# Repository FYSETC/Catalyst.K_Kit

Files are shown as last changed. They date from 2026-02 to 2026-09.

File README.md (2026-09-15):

# Catalyst.K
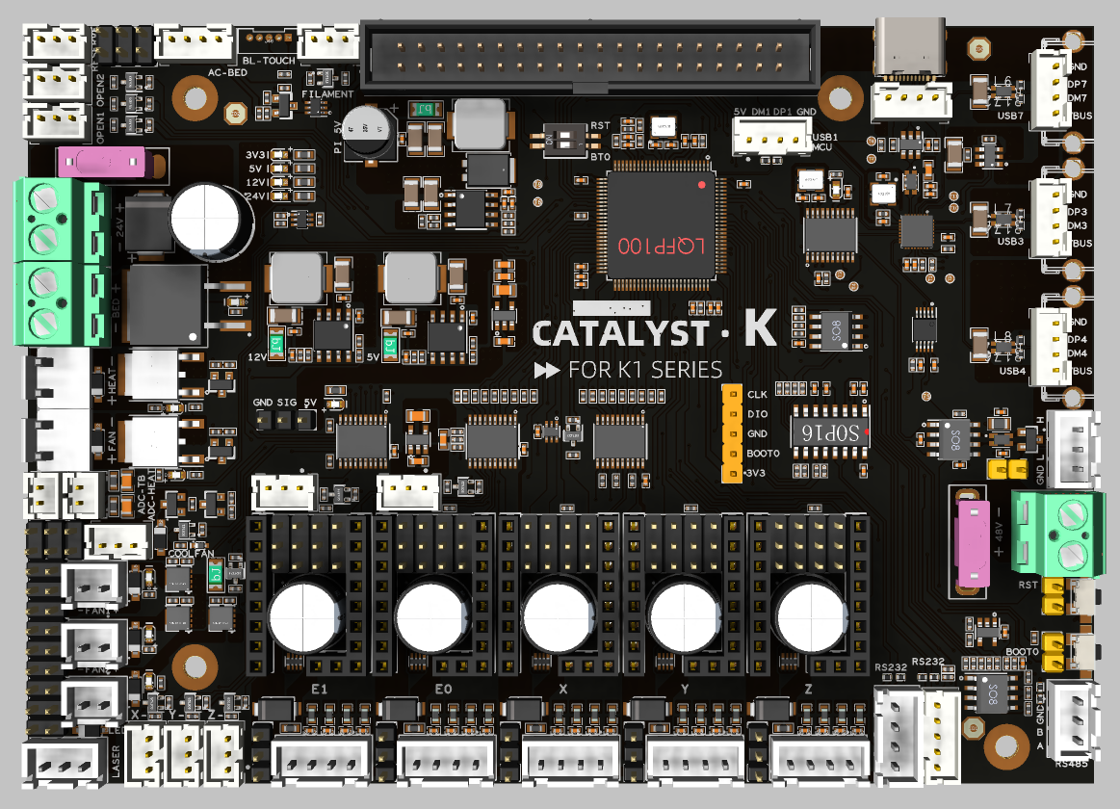
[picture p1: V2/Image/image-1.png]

# Introduction
This high‑performance 3D printer mainboard is built around an STM32H723 32‑bit MCU and comes in a 138 mm × 98 mm form factor. Designed for modern open‑source firmware such as Klipper, it connects to external SBCs like Raspberry Pi 3B+/4B/5B via USB to form a powerful “MCU + SBC” architecture, enabling high‑speed printing, multi‑axis motion control, and advanced feature expansion.

# Features
- High‑performance MCU based on STM32H723 for demanding 3D printing workloads such as high‑speed interpolation and synchronized multi‑axis motion control.
- Native support for Klipper‑style setups via USB connection to Raspberry Pi 3B+/4B/5B or any Klipper‑compatible host.
- Five STEPSTICK sockets supporting flexible driver choices such as TMC5160 and TMC2209 to balance torque, smoothness, and silent operation.
- Selectable 24V/48V stepper motor supply with per‑motor voltage selection for mixed‑voltage motion systems.
- DC 24V input with 24V/10 A heated bed output, AC bed control signal output, and up to 5A hotend heater output for high‑power applications.
- On‑board regulated rails: 12V/3A, 5V/3A, 5V/6A (for Raspberry Pi power), and 3.3V/800 mA to power fans, sensors, and SBCs from a single board.
- Rich connectivity including 3× USB, 2× RS‑232, 1× RS‑485, and 1× high‑speed CAN interface for advanced expansions and distributed motion systems.
- Nine general‑purpose IOs and five fan outputs, with four voltage‑selectable (5V/12V/24V), plus an RGB header for status indication and lighting effects.

-------

# Applications
- Ideal as the main controller for mid‑ to high‑end FDM 3D printers, especially Klipper‑based high‑speed and multi‑axis systems.
- Suitable for upgrading existing printers from legacy 8‑bit or low‑performance boards to an STM32H7 + Klipper platform for higher speed and greater flexibility.
- Can be used in other motion‑control equipment requiring up to five stepper axes, 24 V / 48 V mixed supplies, and rich communication interfaces, such as small CNC machines, automation rigs, and laboratory devices.

# Catalyst.K ToolHead
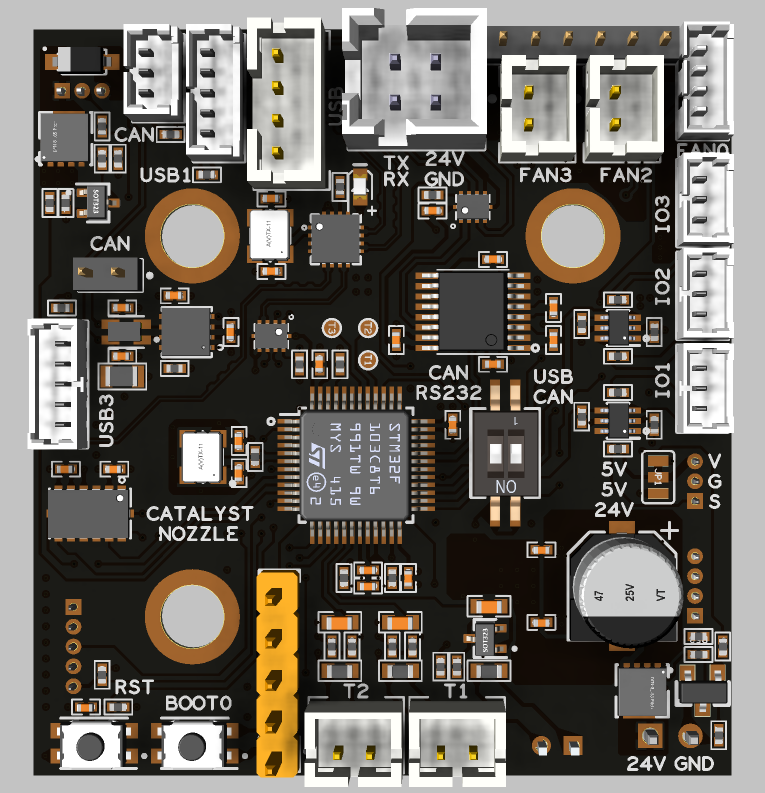
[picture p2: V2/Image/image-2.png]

# Introduction

CATALYST_NOZZLE is a compact Klipper toolboard with a footprint of only 47 mm × 44 mm, designed to be mounted close to the printhead or extruder. It is powered by an STM32G431CBT6 32‑bit MCU and supports multiple communication modes, including USB and CAN / RS‑232, which can be switched via an on‑board physical button.
The board integrates a TMC2209 stepper motor driver, an ADXL345 3‑axis accelerometer, multiple fan and temperature inputs, as well as BL‑Touch and hotend heater control. This greatly simplifies toolhead wiring, reduces cable bundle weight on moving parts, and improves overall reliability and serviceability of the printer.

# Features 
- Compact toolboard design: 47 mm × 44 mm, mounted directly near the printhead or extruder to greatly simplify wiring.
- STM32G431 MCU: 32‑bit high‑performance controller optimized for Klipper multi‑MCU setups.
- Multiple communication modes: Supports USB, CAN, and RS‑232, switchable via on‑board button.
- On‑board USB hub: Provides 3× USB ports and 1× CAN port for easy host and expansion connectivity.
- Integrated TMC2209: On‑board 24V‑powered TMC2209 stepper driver for silent, precise extruder control.
- Built‑in ADXL345: On‑board 3‑axis accelerometer for Klipper input shaping and resonance testing.
- Stable power outputs: 24V input (max. 28V) with on‑board 5V@3A and 3.3V@0.8A rails.
- Rich IO and fan interfaces: 4 level‑shifted IO pins, 4 fan outputs (2×2‑wire with selectable 5V/24V, 1×3‑wire, 1×4‑wire).
- Complete sensing and actuator interfaces: 3 temperature inputs, 1 BL‑Touch connector, 1 hotend heater output up to 2.5A.
- Easy debugging: On‑board BOOT0 and RESET buttons for quick flashing and debugging.

# Applications 
- Used as a Klipper toolhead board for extruder/printhead control, providing local motor drive, temperature control, fan control, and acceleration measurement on the toolhead to greatly simplify the printer’s wiring.
- Suitable for mid‑ to high‑end FDM 3D printers that require integrated TMC2209, ADXL345, BL‑Touch, and multiple fan/temperature interfaces, both for upgrading existing machines and for new printer designs.
- Applicable in multi‑toolhead, multi‑nozzle, or remote‑extrusion setups as a distributed toolboard node, connected to the Klipper host system via CAN or USB /RS‑232 to build flexible multi‑MCU motion control architectures.

# Pin Out

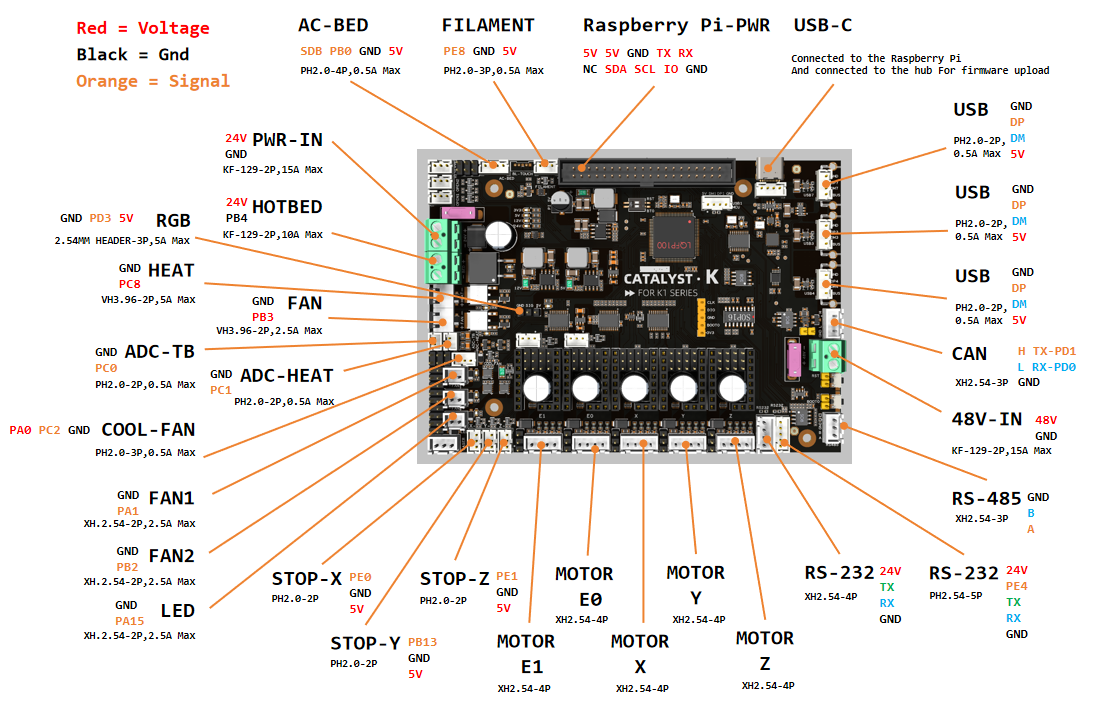
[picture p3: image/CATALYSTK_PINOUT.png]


# Communication Methods
- USB
- CAN
- RS-232

See [Wiki](https://wiki.fysetc.com/docs/CATALYST-K) for specific wiring.
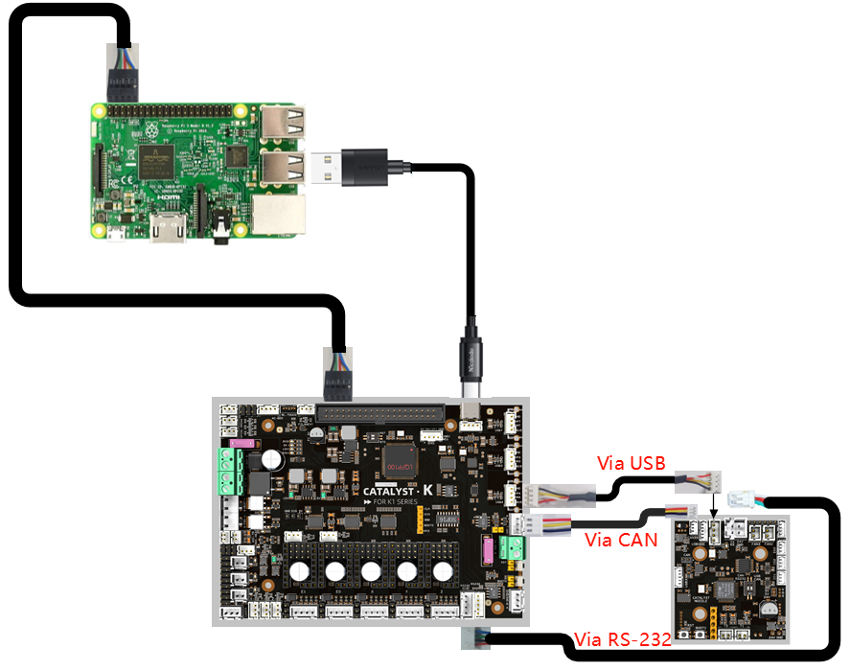
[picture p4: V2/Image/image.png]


# Reference
[Catalyst.K](https://wiki.fysetc.com/docs/CATALYST-K)

[Catalyst.K ToolHead](https://wiki.fysetc.com/docs/Catalyst-K-ToolHead)

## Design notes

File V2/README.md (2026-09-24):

# Catalyst.K
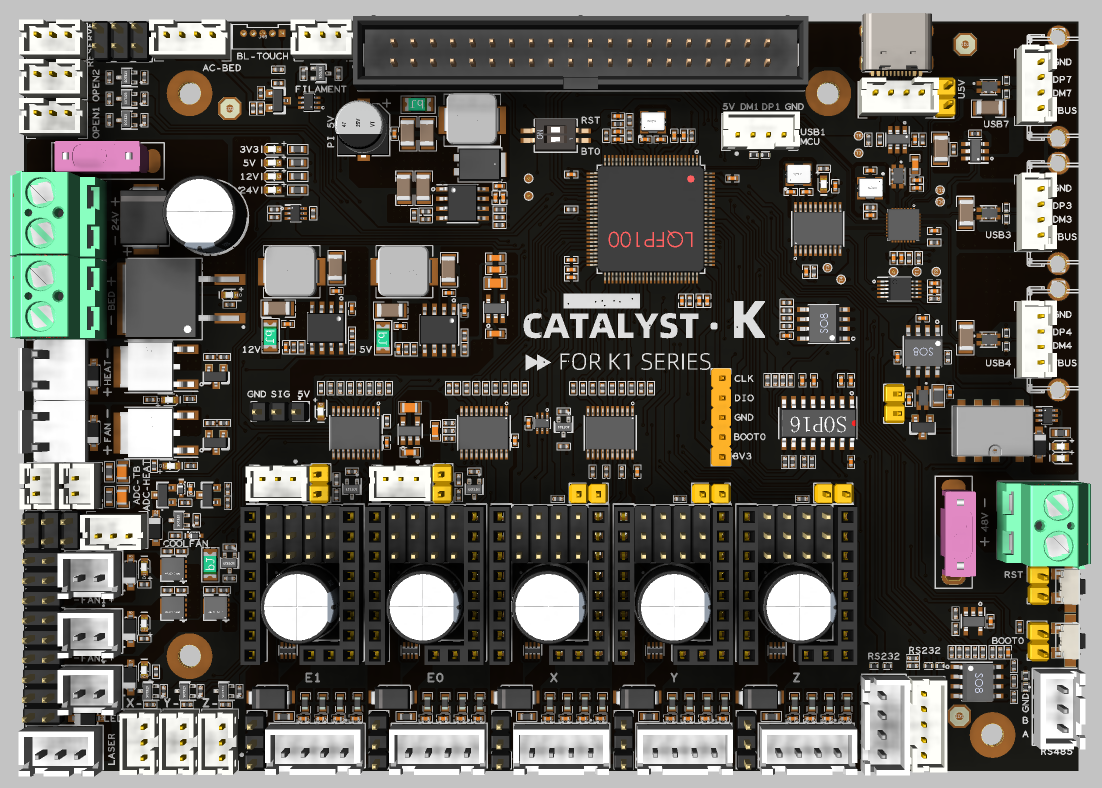
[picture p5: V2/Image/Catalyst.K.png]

## Introduction
This high‑performance 3D printer mainboard is built around an STM32H723 32‑bit MCU and comes in a 138 mm × 98 mm form factor. Designed for modern open‑source firmware such as Klipper, it connects to external SBCs like Raspberry Pi 3B+/4B/5B via USB to form a powerful “MCU + SBC” architecture, enabling high‑speed printing, multi‑axis motion control, and advanced feature expansion.

## Features
- High‑performance MCU based on STM32H723 for demanding 3D printing workloads such as high‑speed interpolation and synchronized multi‑axis motion control.
- Native support for Klipper‑style setups via USB connection to Raspberry Pi 3B+/4B/5B or any Klipper‑compatible host.
- Five STEPSTICK sockets supporting flexible driver choices such as TMC5160 and TMC2209 to balance torque, smoothness, and silent operation.
- Selectable 24V/48V stepper motor supply with per‑motor voltage selection for mixed‑voltage motion systems.
- DC 24V input with 24V/10 A heated bed output, AC bed control signal output, and up to 5A hotend heater output for high‑power applications.
- On‑board regulated rails: 12V/3A, 5V/3A, 5V/6A (for Raspberry Pi power), and 3.3V/800 mA to power fans, sensors, and SBCs from a single board.
- Rich connectivity including 3× USB, 2× RS‑232, 1× RS‑485, and 1× high‑speed CAN interface for advanced expansions and distributed motion systems.
- Nine general‑purpose IOs and five fan outputs, with four voltage‑selectable (5V/12V/24V), plus an RGB header for status indication and lighting effects.

-------

## Applications
- Ideal as the main controller for mid‑ to high‑end FDM 3D printers, especially Klipper‑based high‑speed and multi‑axis systems.
- Suitable for upgrading existing printers from legacy 8‑bit or low‑performance boards to an STM32H7 + Klipper platform for higher speed and greater flexibility.
- Can be used in other motion‑control equipment requiring up to five stepper axes, 24 V / 48 V mixed supplies, and rich communication interfaces, such as small CNC machines, automation rigs, and laboratory devices.

# Catalyst.K ToolHead
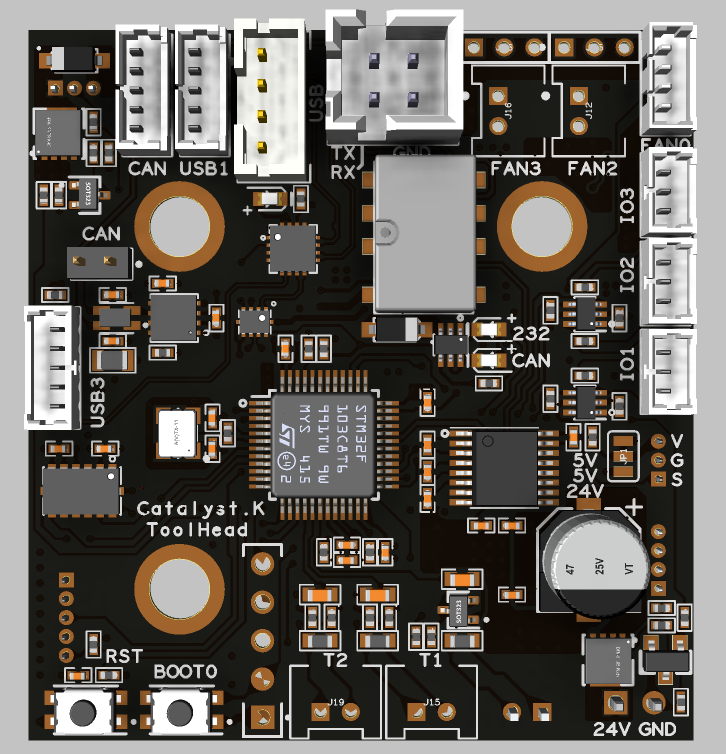
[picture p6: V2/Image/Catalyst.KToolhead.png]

## Introduction

Catalyst.K ToolHead is a compact Klipper toolboard with a footprint of only 47 mm × 44 mm, designed to be mounted close to the printhead or extruder. It is powered by an STM32G431CBT6 32‑bit MCU and supports multiple communication modes, including USB and CAN / RS‑232, which can be switched via an on‑board physical button.
The board integrates a TMC2209 stepper motor driver, an ADXL345 3‑axis accelerometer, multiple fan and temperature inputs, as well as BL‑Touch and hotend heater control. This greatly simplifies toolhead wiring, reduces cable bundle weight on moving parts, and improves overall reliability and serviceability of the printer.

## Features 
- Compact toolboard design: 47 mm × 44 mm, mounted directly near the printhead or extruder to greatly simplify wiring.
- STM32G431 MCU: 32‑bit high‑performance controller optimized for Klipper multi‑MCU setups.
- Multiple communication modes: Supports USB, CAN, and RS‑232, switchable via on‑board button.
- On‑board USB hub: Provides 3× USB ports and 1× CAN port for easy host and expansion connectivity.
- Integrated TMC2209: On‑board 24V‑powered TMC2209 stepper driver for silent, precise extruder control.
- Built‑in ADXL345: On‑board 3‑axis accelerometer for Klipper input shaping and resonance testing.
- Stable power outputs: 24V input (max. 28V) with on‑board 5V@3A and 3.3V@0.8A rails.
- Rich IO and fan interfaces: 4 level‑shifted IO pins, 4 fan outputs (2×2‑wire with selectable 5V/24V, 1×3‑wire, 1×4‑wire).
- Complete sensing and actuator interfaces: 3 temperature inputs, 1 BL‑Touch connector, 1 hotend heater output up to 2.5A.
- Easy debugging: On‑board BOOT0 and RESET buttons for quick flashing and debugging.

## Applications 
- Used as a Klipper toolhead board for extruder/printhead control, providing local motor drive, temperature control, fan control, and acceleration measurement on the toolhead to greatly simplify the printer’s wiring.
- Suitable for mid‑ to high‑end FDM 3D printers that require integrated TMC2209, ADXL345, BL‑Touch, and multiple fan/temperature interfaces, both for upgrading existing machines and for new printer designs.
- Applicable in multi‑toolhead, multi‑nozzle, or remote‑extrusion setups as a distributed toolboard node, connected to the Klipper host system via CAN or USB /RS‑232 to build flexible multi‑MCU motion control architectures.

# Catalyst.K Leveling
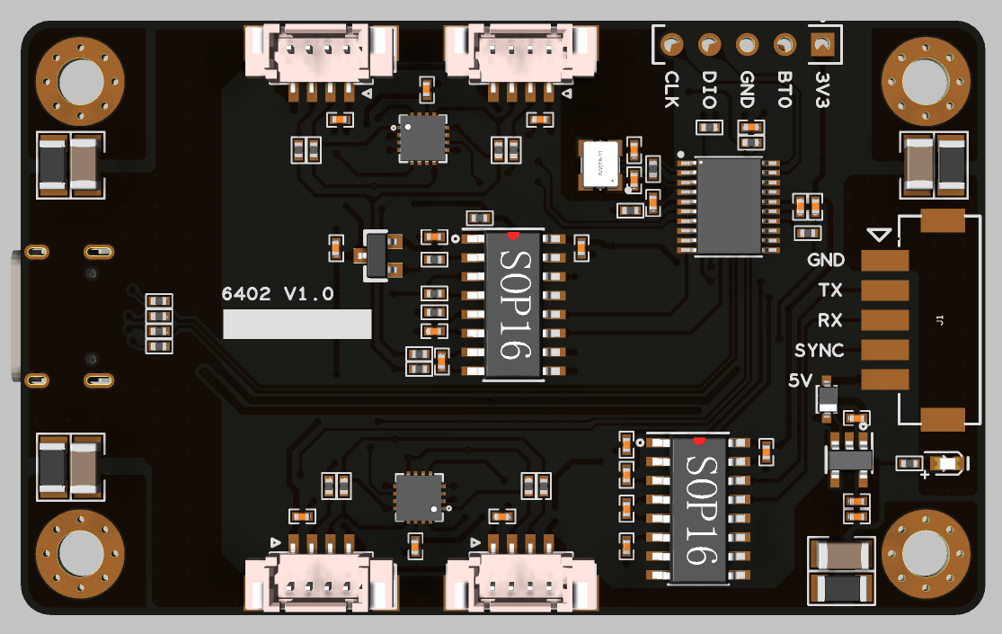
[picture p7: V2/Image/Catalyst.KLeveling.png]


## Introduction
Catalyst.K Leveling is a high-precision leveling control solution designed specifically for 3D printers. Integrating high-precision load cell technology and supporting the Klipper firmware ecosystem, the board achieves superior automatic leveling performance through real-time pressure monitoring, thereby enhancing the quality and stability of the first printed layer.

## Features 
- Main Controller: STM32F042F6P6 (High-performance ARM Cortex-M0 32-bit microcontroller)

- Weighing/Data Acquisition Chip: HX711 (24-bit high-precision A/D converter with built-in voltage regulator)

- Communication Interface: RS-232 standard serial communication

- System Compatibility: Full support for Klipper open-source firmware

- Applications: Automatic bed/nozzle leveling for 3D printers, pressure sensing
## Applications 
- High-Precision Sensing: Equipped with the dedicated HX711 ADC chip, ensuring highly accurate pressure sensing with minimal drift.

- Native Klipper Support: Seamlessly integrates with Klipper systems, utilizing high-speed RS-232 data transmission to meet the demands of high-precision leveling calculations.

- Compact Design: Features a space-efficient layout, making it easy to integrate into various printer configurations.

- Industrial-Grade Control: Powered by a stable STM32 core, ensuring rapid response for leveling operations.
# Catalyst.K Screen
## Catalyst.K Screen RGB
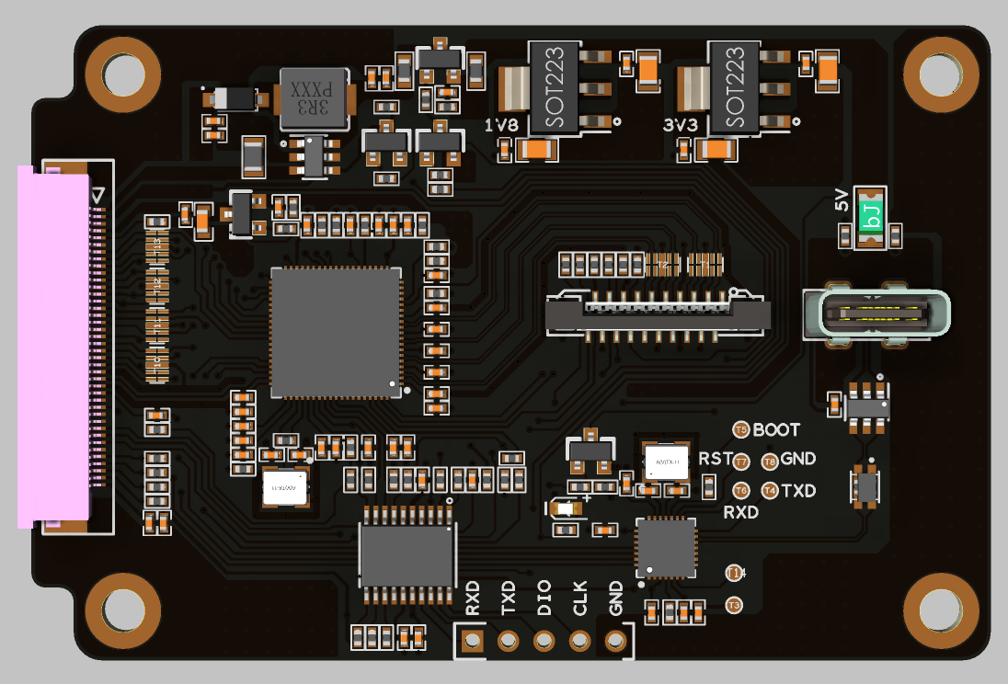
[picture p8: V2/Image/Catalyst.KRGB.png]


## Catalyst.K Screen MIPI
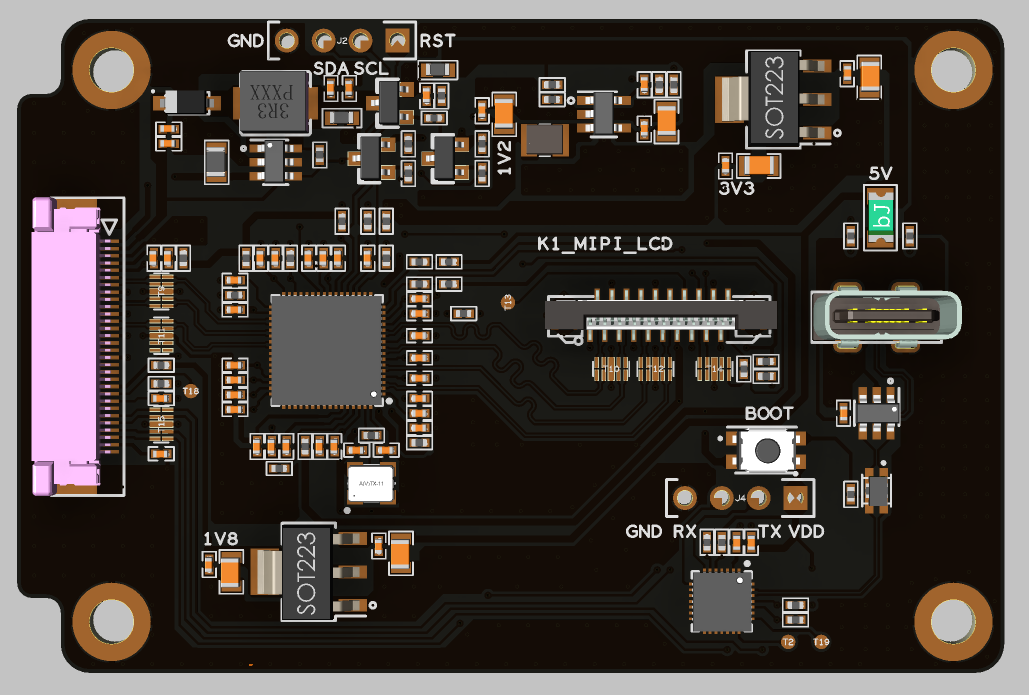
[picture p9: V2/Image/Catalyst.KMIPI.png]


## Introduction

## Features 
-
## Applications 

# Communication Methods
- USB
- CAN
- RS-232

See [Wiki](https://wiki.fysetc.com/docs/CATALYST-K) for specific wiring.


# Reference
[Catalyst.K](https://wiki.fysetc.com/docs/CATALYST-K)

[Catalyst.K ToolHead](https://wiki.fysetc.com/docs/Catalyst-K-ToolHead)

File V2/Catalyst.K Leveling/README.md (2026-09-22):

# Catalyst.K Leveling

## Introduction
Unlike Creality's official leveling MCU, this leveling MCU is used for the official open-source Klipper. Please consult the guide at https://www.klipper3d.org/Load_Cell.html and complete the calibration process before use.

## Firmware Configuration
Catalyst.K LevelingMCU uses the bootloader-free mode by default, and the configuration is as follows:
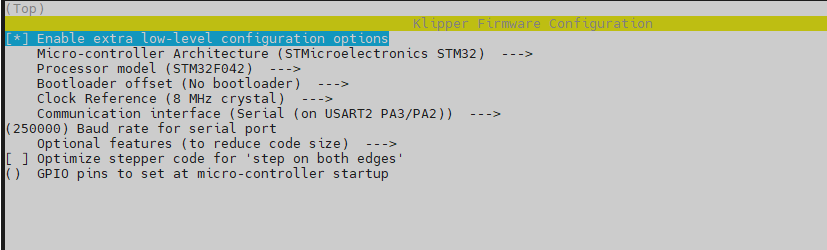
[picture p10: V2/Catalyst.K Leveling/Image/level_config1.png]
 
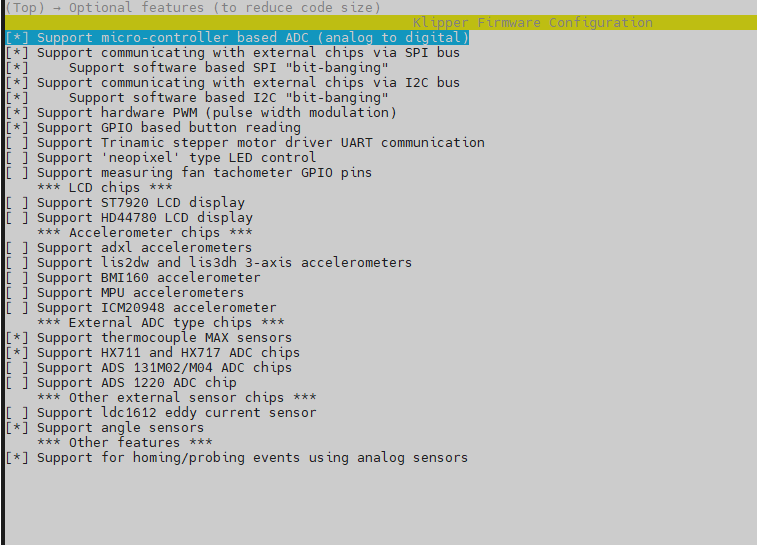
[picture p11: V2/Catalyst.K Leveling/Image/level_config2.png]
 

## Firmware Upload
Use the following commands to compile and upload the firmware.
```
cd ~/klipper
make flash FLASH_DEVICE=0483:df11
```

# Important
During normal operation, PA0, PA1, PA5, and PA6 should all be at a low logic level; please do not set them to a high logic level.

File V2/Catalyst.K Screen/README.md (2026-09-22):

# Catalyst.K Screen
## Introduction
Referring to the Catalyst.K connection diagram, the Catalyst.K Screen is an adapter board positioned between the Raspberry Pi's HDMI port and the original Creality RGB screen.

Once the connections are completed according to the wiring diagram and the Raspberry Pi is configured following the instructions in the "Config" directory, the original display will function correctly.

## RGB
<p align="center">
  
</p>

## MIPI
<p align="center">
  
</p>

# Important
If your RGB screen displays the same image as shown below, this version of the screen adapter board is not compatible.
<p align="center">
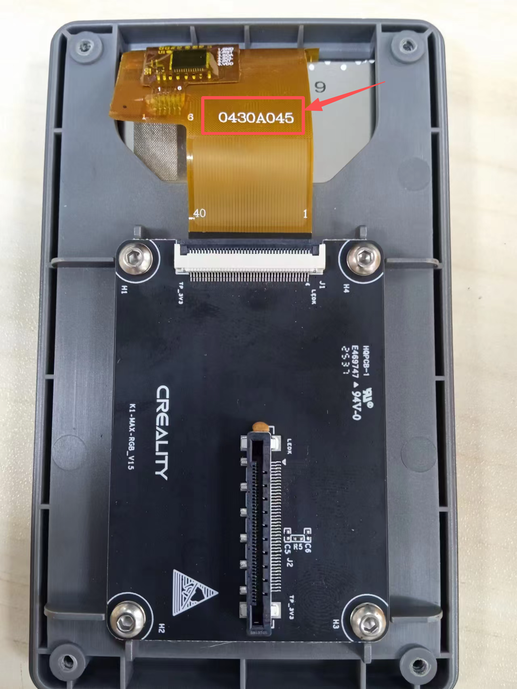
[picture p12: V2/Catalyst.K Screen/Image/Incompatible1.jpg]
  
</p>

<p align="center">
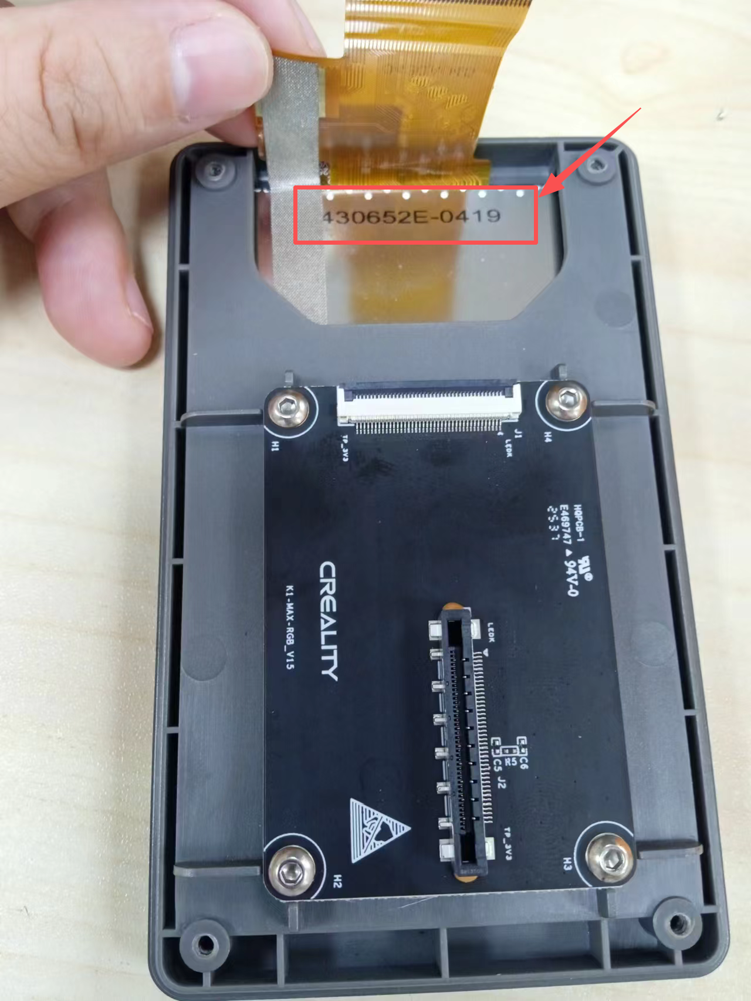
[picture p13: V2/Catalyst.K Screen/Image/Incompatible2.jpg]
  
</p>

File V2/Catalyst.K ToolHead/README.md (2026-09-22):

# Catalyst.K Toolhead

# Introduction
The Catalyst.K Toolhead is a circuit board for extruders. 

# Connection
For connection instructions, please refer to the kit connection diagram. When connecting to other external circuit boards using the following interfaces, please verify that the pinout on the board's backplane matches that of the external circuit board being connected.
<p align="center">
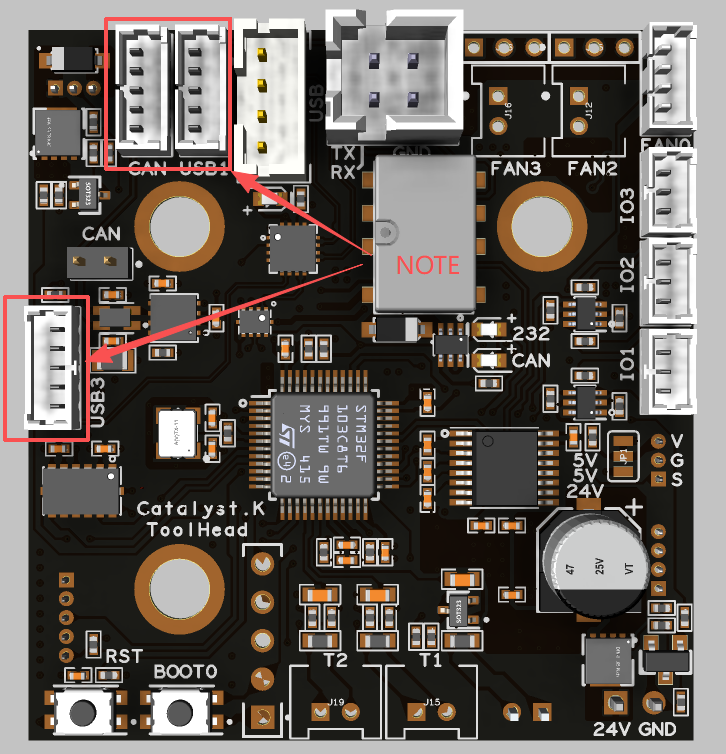
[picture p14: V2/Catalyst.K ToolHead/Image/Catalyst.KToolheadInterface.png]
  
</p>

# Firmware compilation and upload
## Connection
A professional USB cable is included in the kit; connecting the Raspberry Pi to the Catalyst.KToolhead with it enables firmware uploading. Do not use other USB cables unless you have verified that their pinout matches that of the provided cable.
<p align="center">
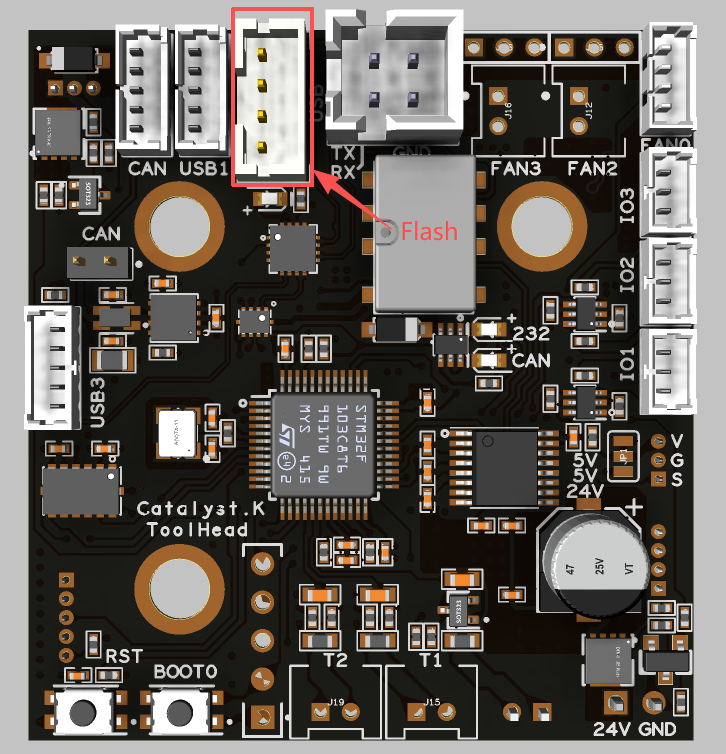
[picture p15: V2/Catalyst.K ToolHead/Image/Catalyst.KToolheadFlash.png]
  
</p>

## Firmware Configuration
### General Klipper
#### Serial
<p align="left">
  
</p>

#### USB
<p align="left">
  
</p>

#### Can
<p align="left">
  
</p>

### K1_Series_Klipper
#### Serial
<p align="left">
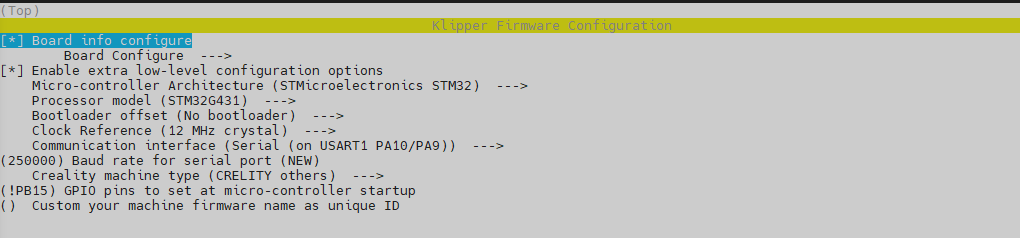
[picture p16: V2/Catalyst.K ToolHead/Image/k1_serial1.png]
  
</p>

<p align="left">
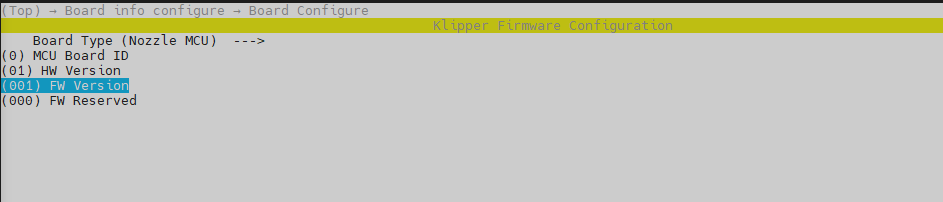
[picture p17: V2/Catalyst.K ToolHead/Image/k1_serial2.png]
  
</p>

#### USB
<p align="left">
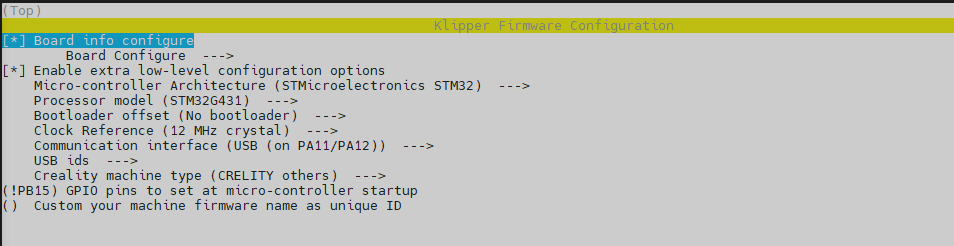
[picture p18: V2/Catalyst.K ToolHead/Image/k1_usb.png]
  
</p>

#### Can
<p align="left">
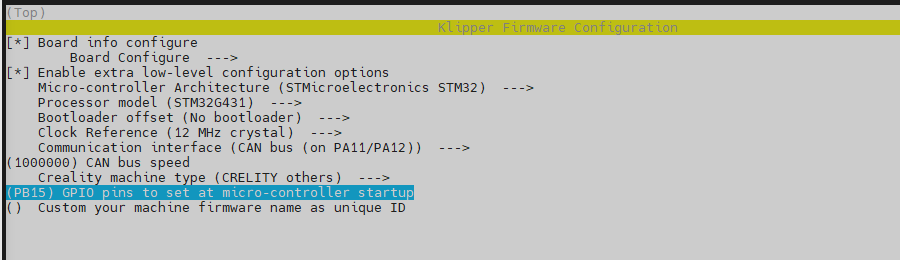
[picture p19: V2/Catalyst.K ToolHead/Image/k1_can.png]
  
</p>

# Firmware Upload
Use the following commands to compile and upload the firmware.
```
cd ~/klipper
make flash FLASH_DEVICE=0483:df11
```

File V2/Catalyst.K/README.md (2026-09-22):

# Catalyst.K

# Introduction
Catalyst.K is the main circuit board installed at the bottom of the machine. For connection instructions, please refer to the kit connection diagram.

# Firmware compilation and upload
## Firmware Configuration
### General Klipper
#### Serial and USB
<p align="left">
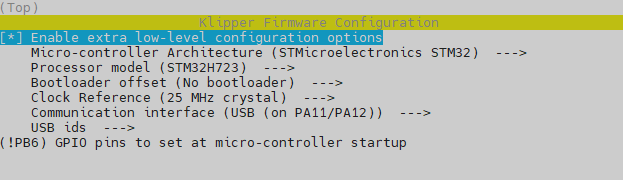
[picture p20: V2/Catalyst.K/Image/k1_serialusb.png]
  
</p>

#### Can
<p align="left">
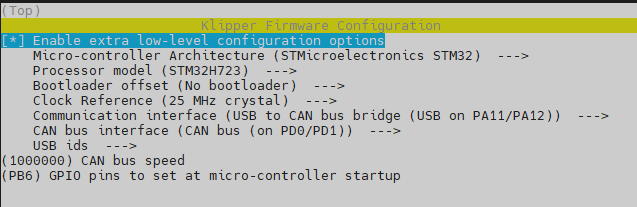
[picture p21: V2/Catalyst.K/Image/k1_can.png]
  
</p>

### K1_Series_Klipper
#### Serial and USB
<p align="left">
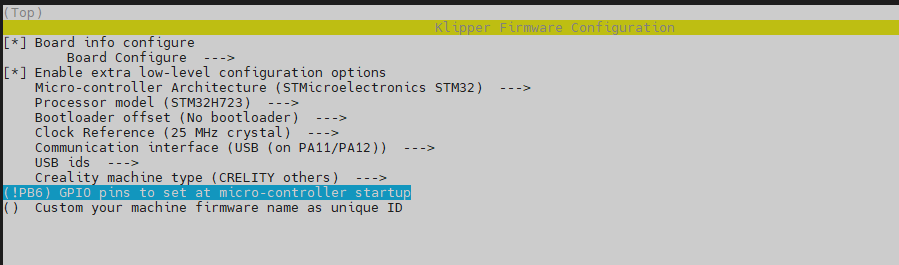
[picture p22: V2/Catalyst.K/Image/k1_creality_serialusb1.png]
  
</p>

<p align="left">
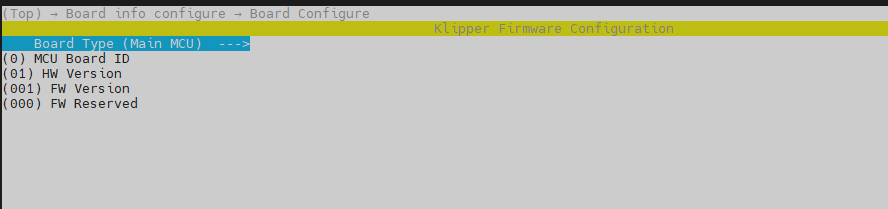
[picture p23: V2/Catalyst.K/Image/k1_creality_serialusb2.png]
  
</p>

#### Can
<p align="left">
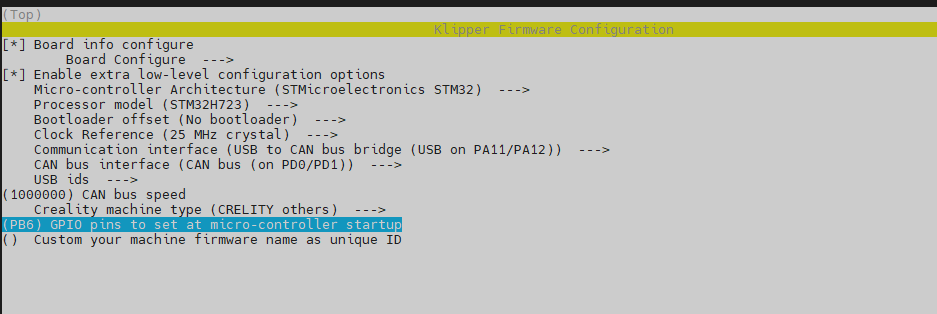
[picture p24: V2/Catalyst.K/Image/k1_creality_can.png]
  
</p>

# Firmware Upload
Use the following commands to compile and upload the firmware.
```
cd ~/klipper
make flash FLASH_DEVICE=0483:df11
```

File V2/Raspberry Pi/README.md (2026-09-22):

# Catalyst.K Raspberry Pi
## Introduction
The Raspberry Pi 3, 4, and 5 are all compatible with the Catalyst.K kit. You can use either the Creality open-source version or the official version of Klipper. 

##  General Klipper
Please refer to https://github.com/dw-0/kiauh to complete the installation. When using General Klipper, you must use the Catalyst.K Leveling included in the kit.

## K1_Series_Klipper
Please refer to https://github.com/bean22-dev/K1_Series_Klipper to complete the installation. The Catalyst.K and Catalyst.K ToolHead circuit boards on the original machine can be replaced individually. When using K1_Series_Klipper, you must use the creality Leveling board.

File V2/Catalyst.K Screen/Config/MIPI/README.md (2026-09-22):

# Catalyst.K ScreenMIPI Raspberry Config

## Kernel Version
Please execute the following command to check the Raspberry Pi firmware version.
```
cat /etc/os-release
```
The system being queried is the Bullseye or Trixie version.

## Bullseye
###  Display Config
#### cmdline.txt
cmdline.txt is typically located in the /boot/firmware directory or the /boot directory. Add the following command to the command line.
```
usbhid.quirks=0x27c0:0x0859:0x00001408 dwc_otg.fiq_fsm_enable=0 video=HDMI-A-1:480x800@60 fbcon=rotate:1
```

#### config.txt
config.txt is typically located in the /boot/firmware directory or the /boot directory. Add the following command to the command line.
```
dtoverlay=vc4-kms-v3d  # ensure this line of configuration is set.
# add the following configuration line.
hdmi_force_hotplug=1
hdmi_group=2
hdmi_mode=87
hdmi_drive=1
hdmi_timings=480 0 40 64 88 800 1 10 20 35 0 0 0 53 0 31000000 6
display_hdmi_rotate=2
```

### Touch Configuration
#### 99-wch-touch.rules
Create the rule file using the following command:
```
sudo nano /etc/udev/rules.d/99-wch-touch.rules
```
Save the following content to the file `99-wch-touch.rules`:
```
ACTION=="add|change", SUBSYSTEM=="input", KERNEL=="event*", \
  ATTRS{name}=="Cadwell Laboratories, Inc. TouchScreen", \
  ENV{ID_INPUT}="1", \
  ENV{ID_INPUT_MOUSE}="1"
```

#### 99-cadwell-pointer.conf
Create the config file using the following command:
```
sudo nano /etc/X11/xorg.conf.d/99-cadwell-pointer.conf
```
Save the following content to the file `99-cadwell-pointer.conf`:
```
Section "InputClass"
    Identifier           "Cadwell abs evdev"
    MatchProduct         "Cadwell Laboratories, Inc. TouchScreen"
    MatchUSBID           "27c0:0859"
    MatchDevicePath      "/dev/input/event*"
    Driver               "evdev"
    Option "Ignore"      "off"
    Option "Mode"        "Absolute"
    Option "SwapAxes"    "off"
    Option "InvertX"     "off"
    Option "InvertY"     "off"
    Option "TransformationMatrix" "1 0 0 0 1 0 0 0 1"
EndSection
```

#### 10-monitor.conf
Create the config file using the following command:
```
sudo nano /etc/X11/xorg.conf.d/10-monitor.conf
```
Save the following content to the file `10-monitor.conf:
```
Section "Device"
    Identifier "Card0"
    Driver     "modesetting"
EndSection

Section "Monitor"
    Identifier "HDMI-1"
    ModeLine   "480x800" 30.00 480 528 576 656 800 810 820 914 -hsync +vsync
    Option     "PreferredMode" "480x800"
    Option     "Rotate"        "right"
EndSection

Section "Monitor"
    Identifier "HDMI-A-1"
    ModeLine   "480x800" 30.00 480 528 576 656 800 810 820 914 -hsync +vsync
    Option     "PreferredMode" "480x800"
    Option     "Rotate"        "right"
EndSection

Section "Screen"
    Identifier "Screen0"
    Device     "Card0"
    Monitor    "HDMI-1"
    SubSection "Display"
        Modes "480x800"
    EndSubSection
EndSection
```

Use the following command to apply the touch configuration:
```
sudo udevadm control --reload-rules
sudo udevadm trigger
sudo reboot
```

#### KlipperScreen.conf
The following configuration prevents the screen from turning off and is the recommended way to work.
```
#~# screen_blanking = off
#~# screen_blanking_printing = off
#~# use_dpms = False
```

The following configuration will turn off the display, but it will not turn off the screen backlight.
```
#~# screen_blanking = 300
#~# screen_blanking_printing = 300
#~# use_dpms = False
```

The following configuration turns off the display and the screen backlight, but there is a time lag when waking the device via touch.
```
#~# screen_blanking = 300
#~# screen_blanking_printing = 300
#~# use_dpms: True
```

## Trixie
###  Display Config
#### cmdline.txt
cmdline.txt is typically located in the /boot/firmware directory or the /boot directory. Add the following command to the command line.
```
usbhid.quirks=0x27c0:0x0859:0x00001408 dwc_otg.fiq_fsm_enable=0 video=HDMI-A-1:480x800@60 fbcon=rotate:1
```

#### config.txt
config.txt is typically located in the /boot/firmware directory or the /boot directory. Add the following command to the command line.
```
dtoverlay=vc4-kms-v3d  # ensure this line of configuration is set.
# add the following configuration line.
hdmi_force_hotplug=1
hdmi_group=2
hdmi_mode=87
hdmi_drive=1
hdmi_timings=480 0 40 64 88 800 1 10 20 35 0 0 0 53 0 31000000 6
display_hdmi_rotate=2
```

### Touch Configuration
#### 99-wch-touch.rules
Create the rule file using the following command:
```
sudo nano /etc/udev/rules.d/99-wch-touch.rules
```
Save the following content to the file `99-wch-touch.rules`:
```
ACTION=="add|change", SUBSYSTEM=="input", KERNEL=="event*", \
  ATTRS{name}=="Cadwell Laboratories, Inc. TouchScreen", \
  ENV{ID_INPUT}="1", \
  ENV{ID_INPUT_MOUSE}="1"

ACTION=="add|change", SUBSYSTEM=="input", KERNEL=="event*", \
  ATTRS{idVendor}=="27c0", ATTRS{idProduct}=="0859", \
  ENV{ID_INPUT}="1", \
  ENV{ID_INPUT_MOUSE}="1"
```

#### 99-cadwell-pointer.conf
Create the config file using the following command:
```
sudo nano /etc/X11/xorg.conf.d/99-cadwell-pointer.conf
```
Save the following content to the file `99-cadwell-pointer.conf`:
```
Section "InputClass"
    Identifier           "Cadwell abs evdev"
    MatchProduct         "Cadwell Laboratories, Inc. TouchScreen"
    MatchUSBID           "27c0:0859"
    MatchDevicePath      "/dev/input/event*"
    Driver               "evdev"
    Option "Ignore"      "off"
    Option "Mode"        "Absolute"
    Option "SwapAxes"    "off"
    Option "InvertX"     "off"
    Option "InvertY"     "off"
    Option "TransformationMatrix" "1 0 0 0 1 0 0 0 1"
EndSection

```

#### 10-monitor.conf
Create the config file using the following command:
```
sudo nano /etc/X11/xorg.conf.d/10-monitor.conf
```
Save the following content to the file `10-monitor.conf:
```
Section "Device"
    Identifier "Card0"
    Driver     "modesetting"
EndSection

Section "Monitor"
    Identifier "HDMI-1"
    ModeLine   "480x800" 30.00 480 528 576 656 800 810 820 914 -hsync +vsync
    Option     "PreferredMode" "480x800"
    Option     "Rotate"        "right"
EndSection

Section "Monitor"
    Identifier "HDMI-1"
    ModeLine   "480x800" 30.00 480 528 576 656 800 810 820 914 -hsync +vsync
    Option     "PreferredMode" "480x800"
    Option     "Rotate"        "right"
EndSection

Section "Screen"
    Identifier "Screen0"
    Device     "Card0"
    Monitor    "HDMI-1"
    SubSection "Display"
        Modes "480x800"
    EndSubSection
EndSection
```

Use the following command to apply the touch configuration:
```
sudo udevadm control --reload-rules
sudo udevadm trigger
sudo reboot
```

#### KlipperScreen.conf
The following configuration prevents the screen from turning off and is the recommended way to work.
```
#~# screen_blanking = off
#~# screen_blanking_printing = off
#~# use_dpms = False
```

The following configuration will turn off the display, but it will not turn off the screen backlight.
```
#~# screen_blanking = 300
#~# screen_blanking_printing = 300
#~# use_dpms = False
```

The following configuration turns off the display and the screen backlight, but there is a time lag when waking the device via touch.
```
#~# screen_blanking = 300
#~# screen_blanking_printing = 300
#~# use_dpms: True
```

## Important
Please do not directly replace the corresponding files on your Raspberry Pi with the configuration files found in the `Example` directory.

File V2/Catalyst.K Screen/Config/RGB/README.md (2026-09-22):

# Catalyst.K ScreenRGB Raspberry Config

## Display Config
### cmdline.txt
cmdline.txt is typically located in the /boot/firmware directory or the /boot directory. Add the following command to the command line.
```
video=HDMI-1:480x800M@60,rotate=90
```

### config.txt
config.txt is typically located in the /boot/firmware directory or the /boot directory. Add the following command to the command line.
```
#dtoverlay=vc4-kms-v3d  # Comment out this line.
# add the following configuration line.
hdmi_force_hotplug=1
hdmi_group=2
hdmi_mode=87
hdmi_drive=1
hdmi_timings=480 0 40 64 88 800 1 10 20 35 0 0 0 53 0 31000000 6
display_hdmi_rotate=1
```

## Klipper
## Touch Configuration
Create the rule file using the following command:
```
sudo nano /etc/udev/rules.d/99-wch-touch.rules
```
Save the following content to the file `99-wch-touch.rules`:
```
ACTION=="add|change", KERNEL=="event*", ATTRS{name}=="wch.cn TouchScreen", ENV{LIBINPUT_CALIBRATION_MATRIX}="0 1 0 -1 0 1 0 0 1"
```
Use the following command to apply the touch configuration:
```
sudo udevadm control --reload-rules
sudo udevadm trigger
sudo reboot
```

## KlipperScreen.conf
The following configuration will turn off the display, but it will not turn off the screen backlight. Changing the configuration to something else may cause other display issues.
```
#~# screen_blanking = 300
#~# screen_blanking_printing = 300
#~# use_dpms = False
```

## Important
Please do not directly replace the corresponding files on your Raspberry Pi with the configuration files found in the `Example` directory.

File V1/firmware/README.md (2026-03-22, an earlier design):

Please use the setting below to create the firmware for the Catalyst K board. The !PB4 line is important to prevent the Heated Bed from heating at boot. Please do this when you receive the board as a matter of the install.

HOWEVER be aware that going into DFU mode will renable the bed.
**It is therefore important to not to connect any heaters, during the flashing firmware process**

USB



CAN

imageCAN

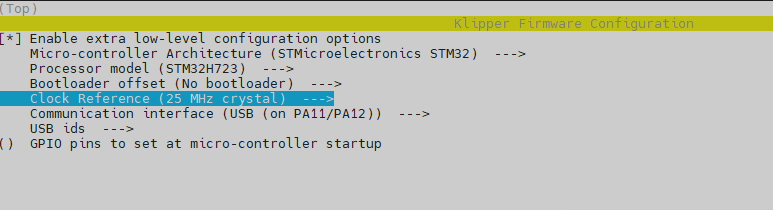
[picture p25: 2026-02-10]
image/catalyst_usb.png

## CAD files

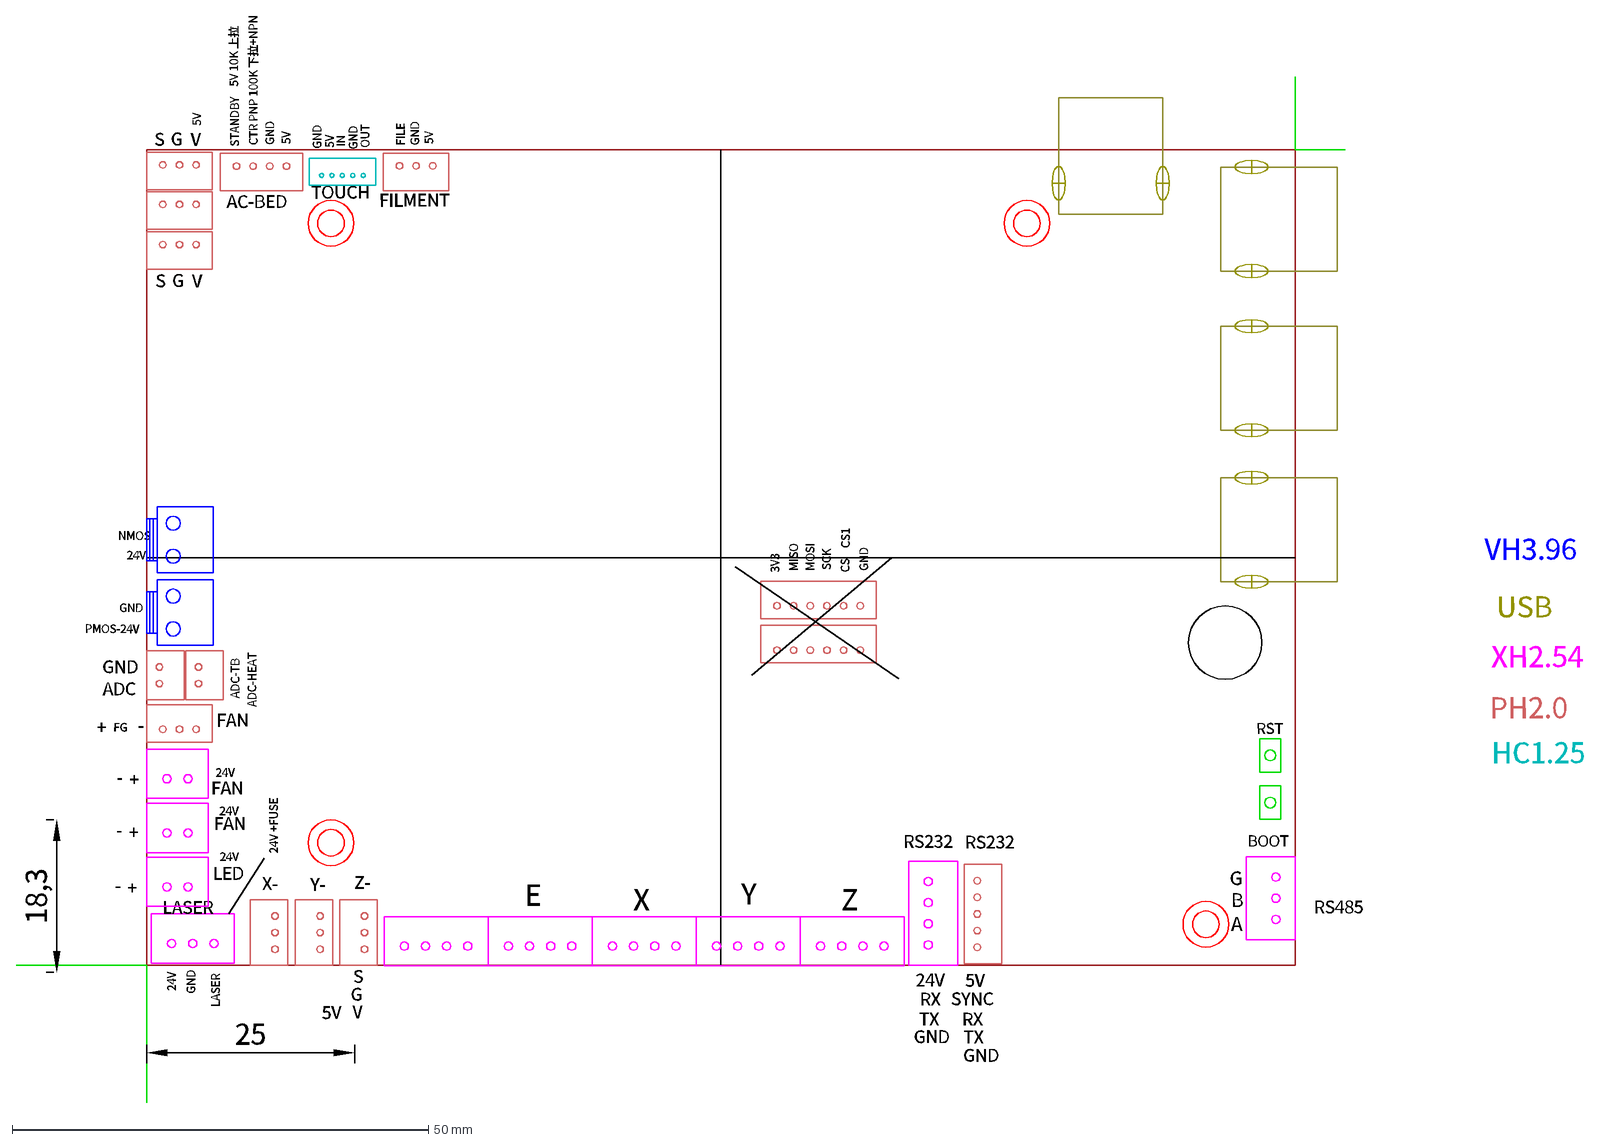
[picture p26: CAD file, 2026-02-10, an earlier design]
V1/CAD/Catalyst_K/Catalyst.K Connector Instruction.dxf
RST
BOOT
RS485
G
B
A
E
Z
Y
X
RS232
X-
Y-
Z-
LASER
FILMENT
TOUCH
AC-BED
LED
FAN
ADC-TB
ADC-HEAT
XH2.54
USB
HC1.25
24V
RX
TX
GND
5V
SYNC
S
V
+
-
ADC
STANDBY
CTR PNP 100K 下拉+NPN
OUT
IN
FILE
3V3
MISO
MOSI
SCK
CS
CS1
PH2.0
NMOS
PMOS-24V
5V 10K 上拉
24V +FUSE
25
18,3
VH3.96
FG

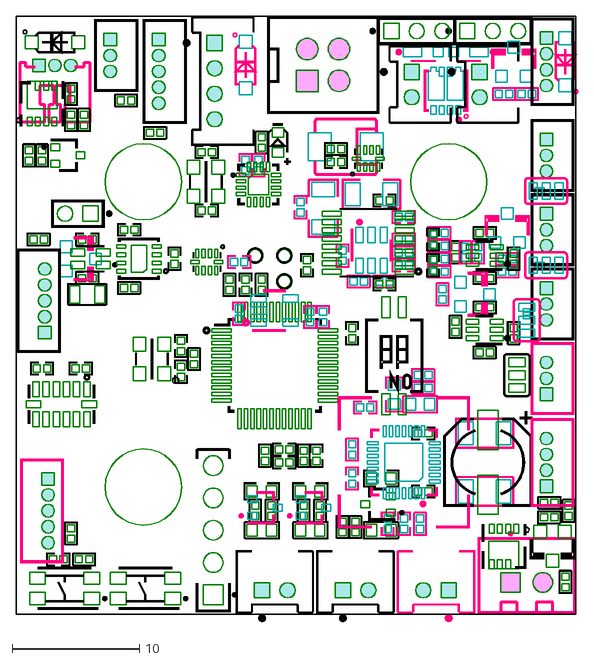
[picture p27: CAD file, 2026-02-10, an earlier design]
V1/CAD/ToolHead/Catalyst.K_ToolHead_2D.dxf
44.2 x 47.6

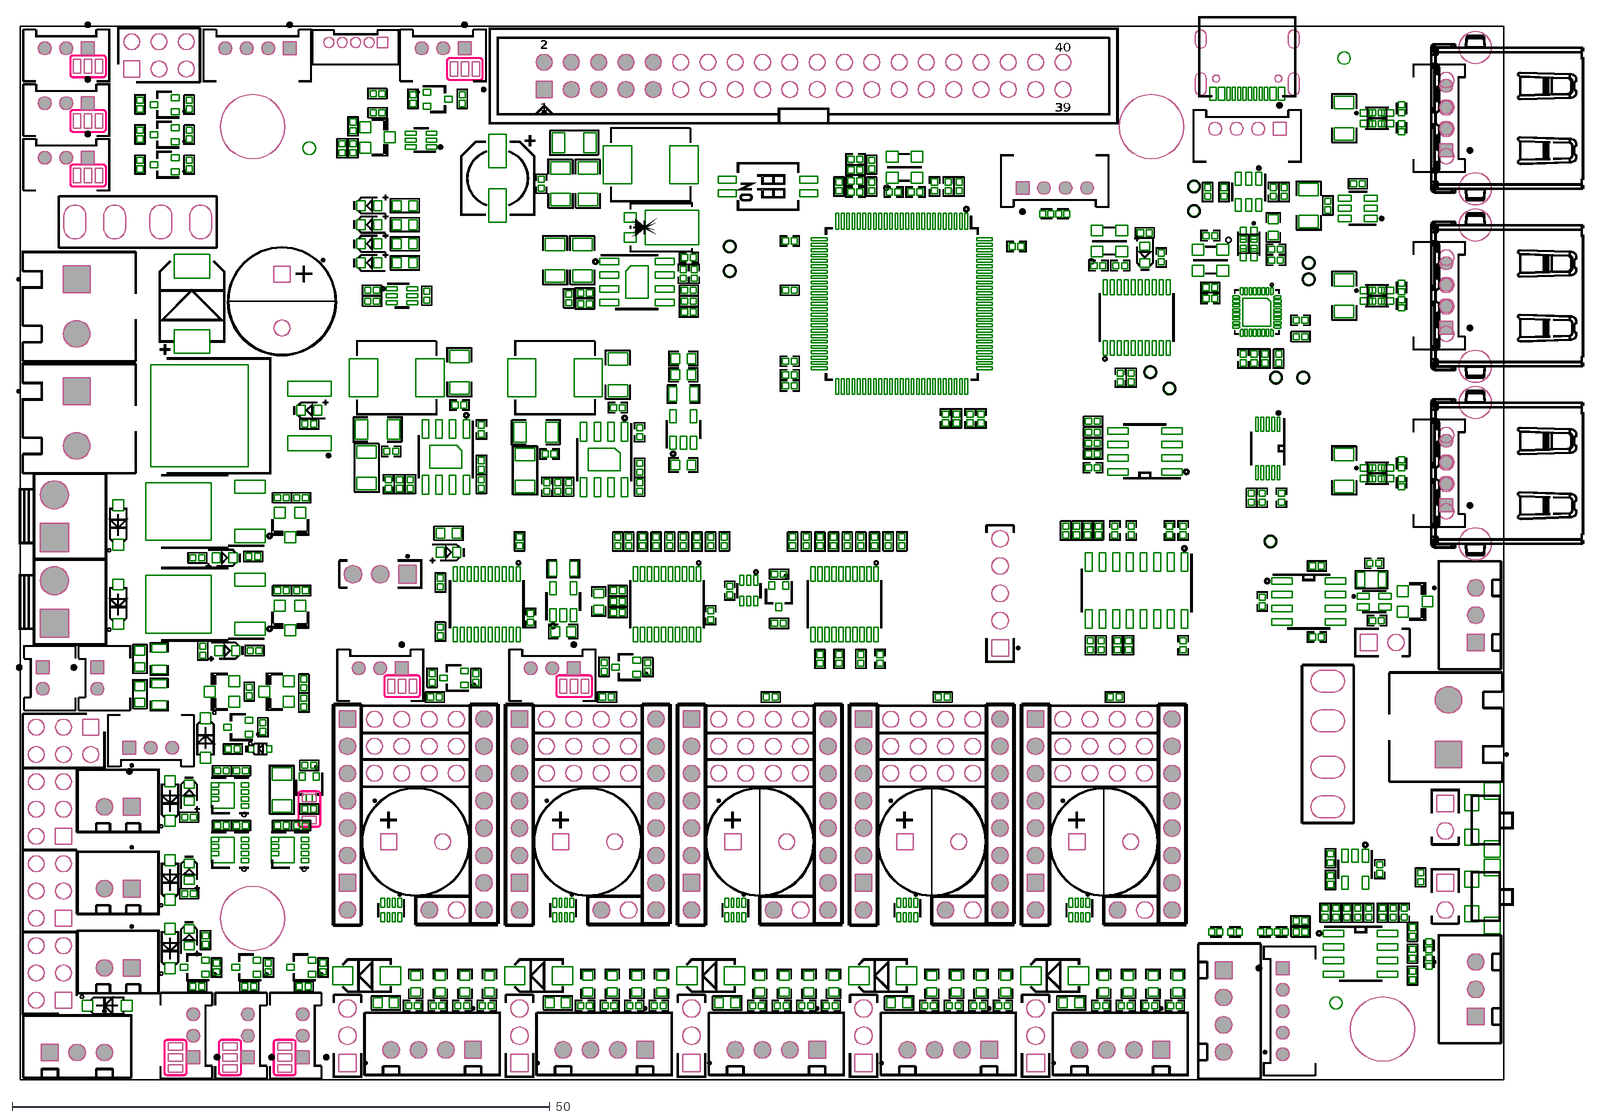
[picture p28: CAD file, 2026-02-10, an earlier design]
V1/CAD/Catalyst_K/Catalyst.K_2D.dxf
1
2
39
40

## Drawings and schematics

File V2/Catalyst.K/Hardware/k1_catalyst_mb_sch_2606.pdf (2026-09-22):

5

4

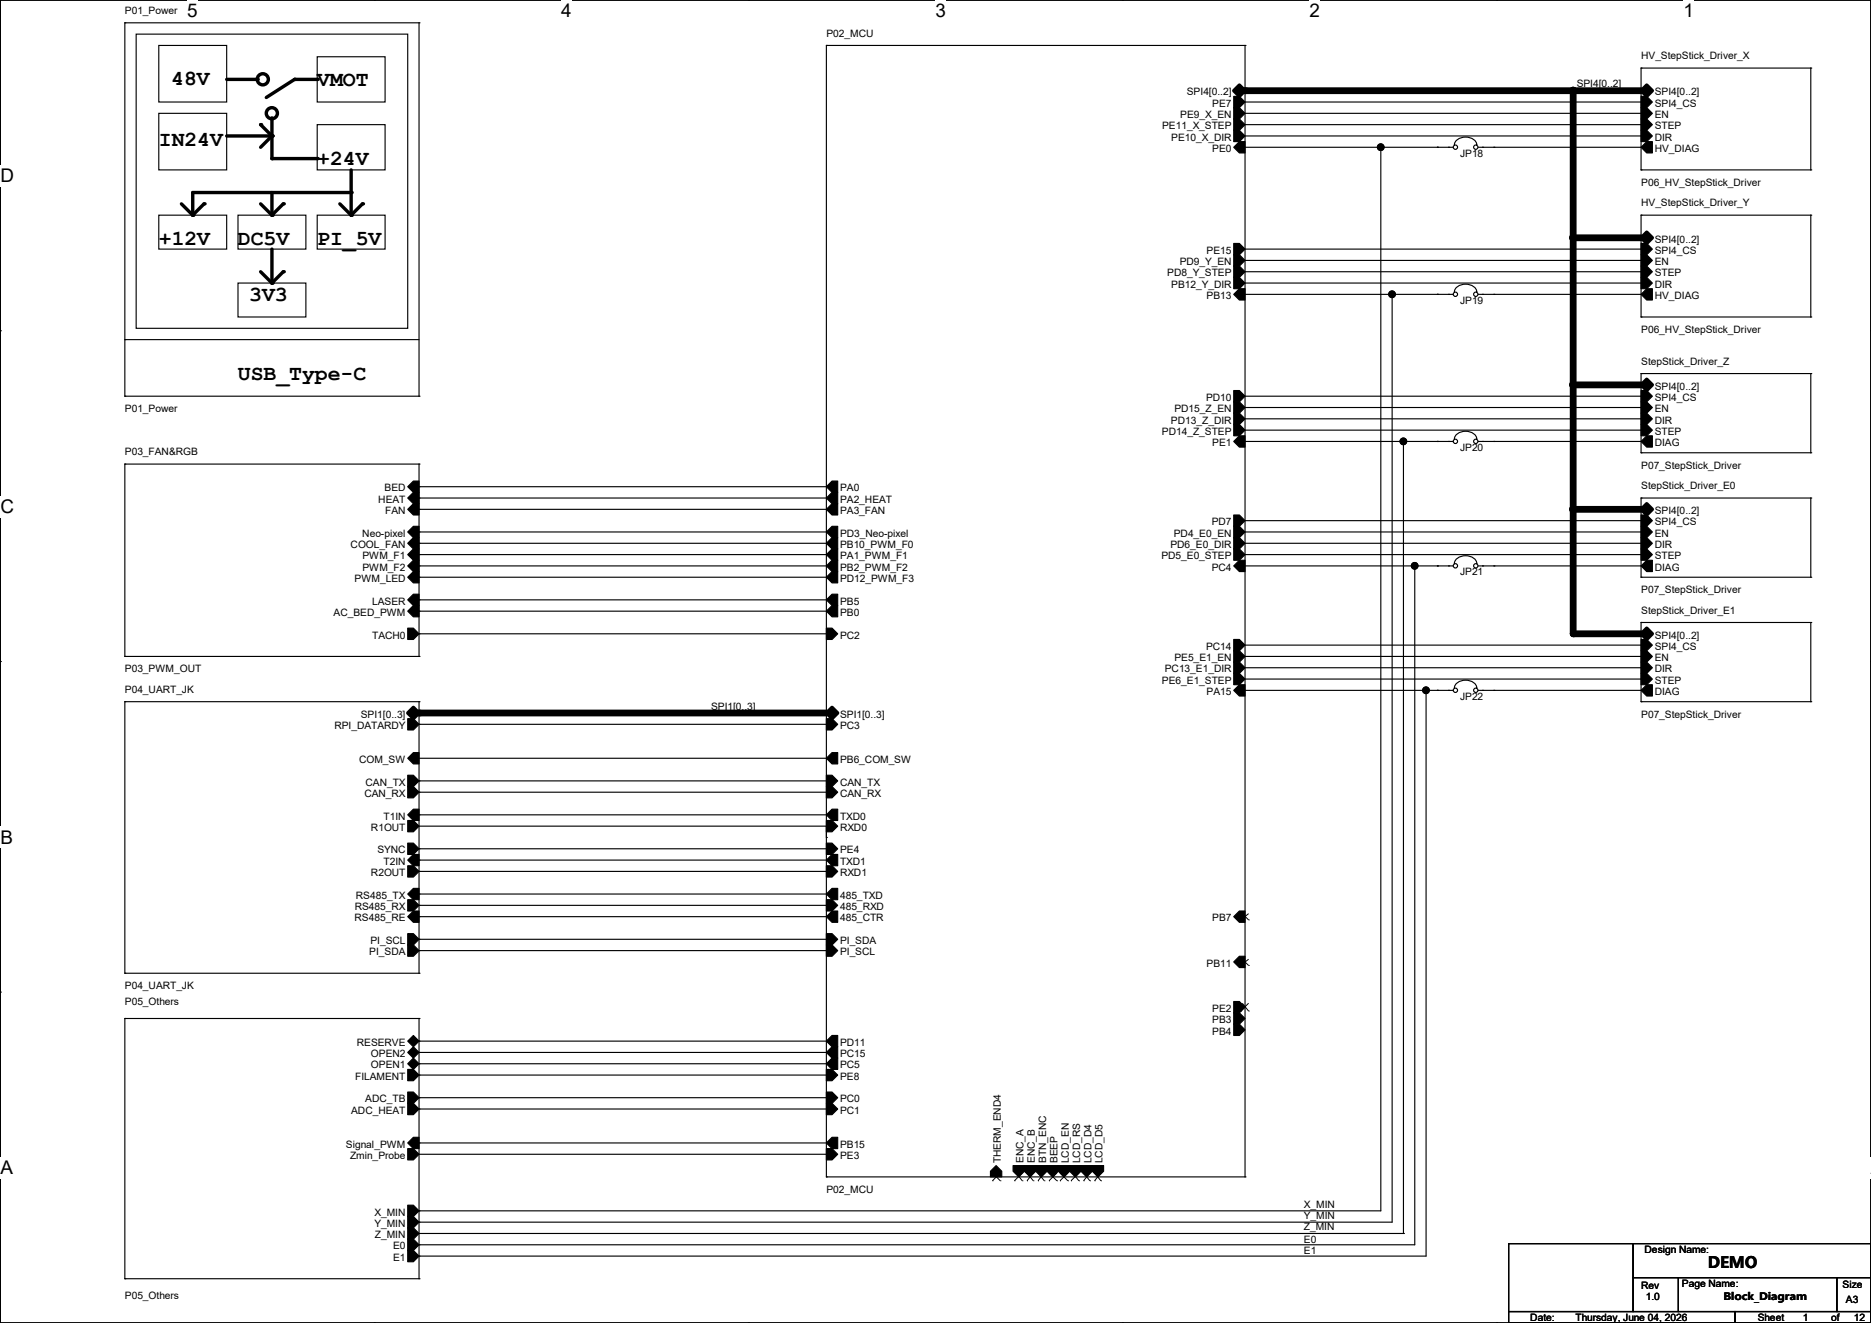
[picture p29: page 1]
VMOT; USB_Type-C; Design Name:; Rev; Page Name:; Size; Date:; Sheet; DEMO; Thursday, June 04, 2026; Block_Diagram; P04_UART_JK; CAN_TX CAN_RX; SPI1[0..3]; PI_SCL PI_SDA; R1OUT; R2OUT; SYNC; RPI_DATARDY; COM_SW; StepStick_Driver_E1; P07_StepStick_Driver; STEP; DIR; SPI4_CS; DIAG; SPI4[0..2]; P05_Others; X_MIN Y_MIN Z_MIN; OPEN2; FILAMENT; Zmin_Probe; OPEN1; Signal_PWM; RESERVE; ADC_TB ADC_HEAT; P01_Power; StepStick_Driver_Z; HV_StepStick_Driver_X; P06_HV_StepStick_Driver; HV_DIAG; EN STEP DIR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

5 | 4 | 3 | 2 | 1

D D

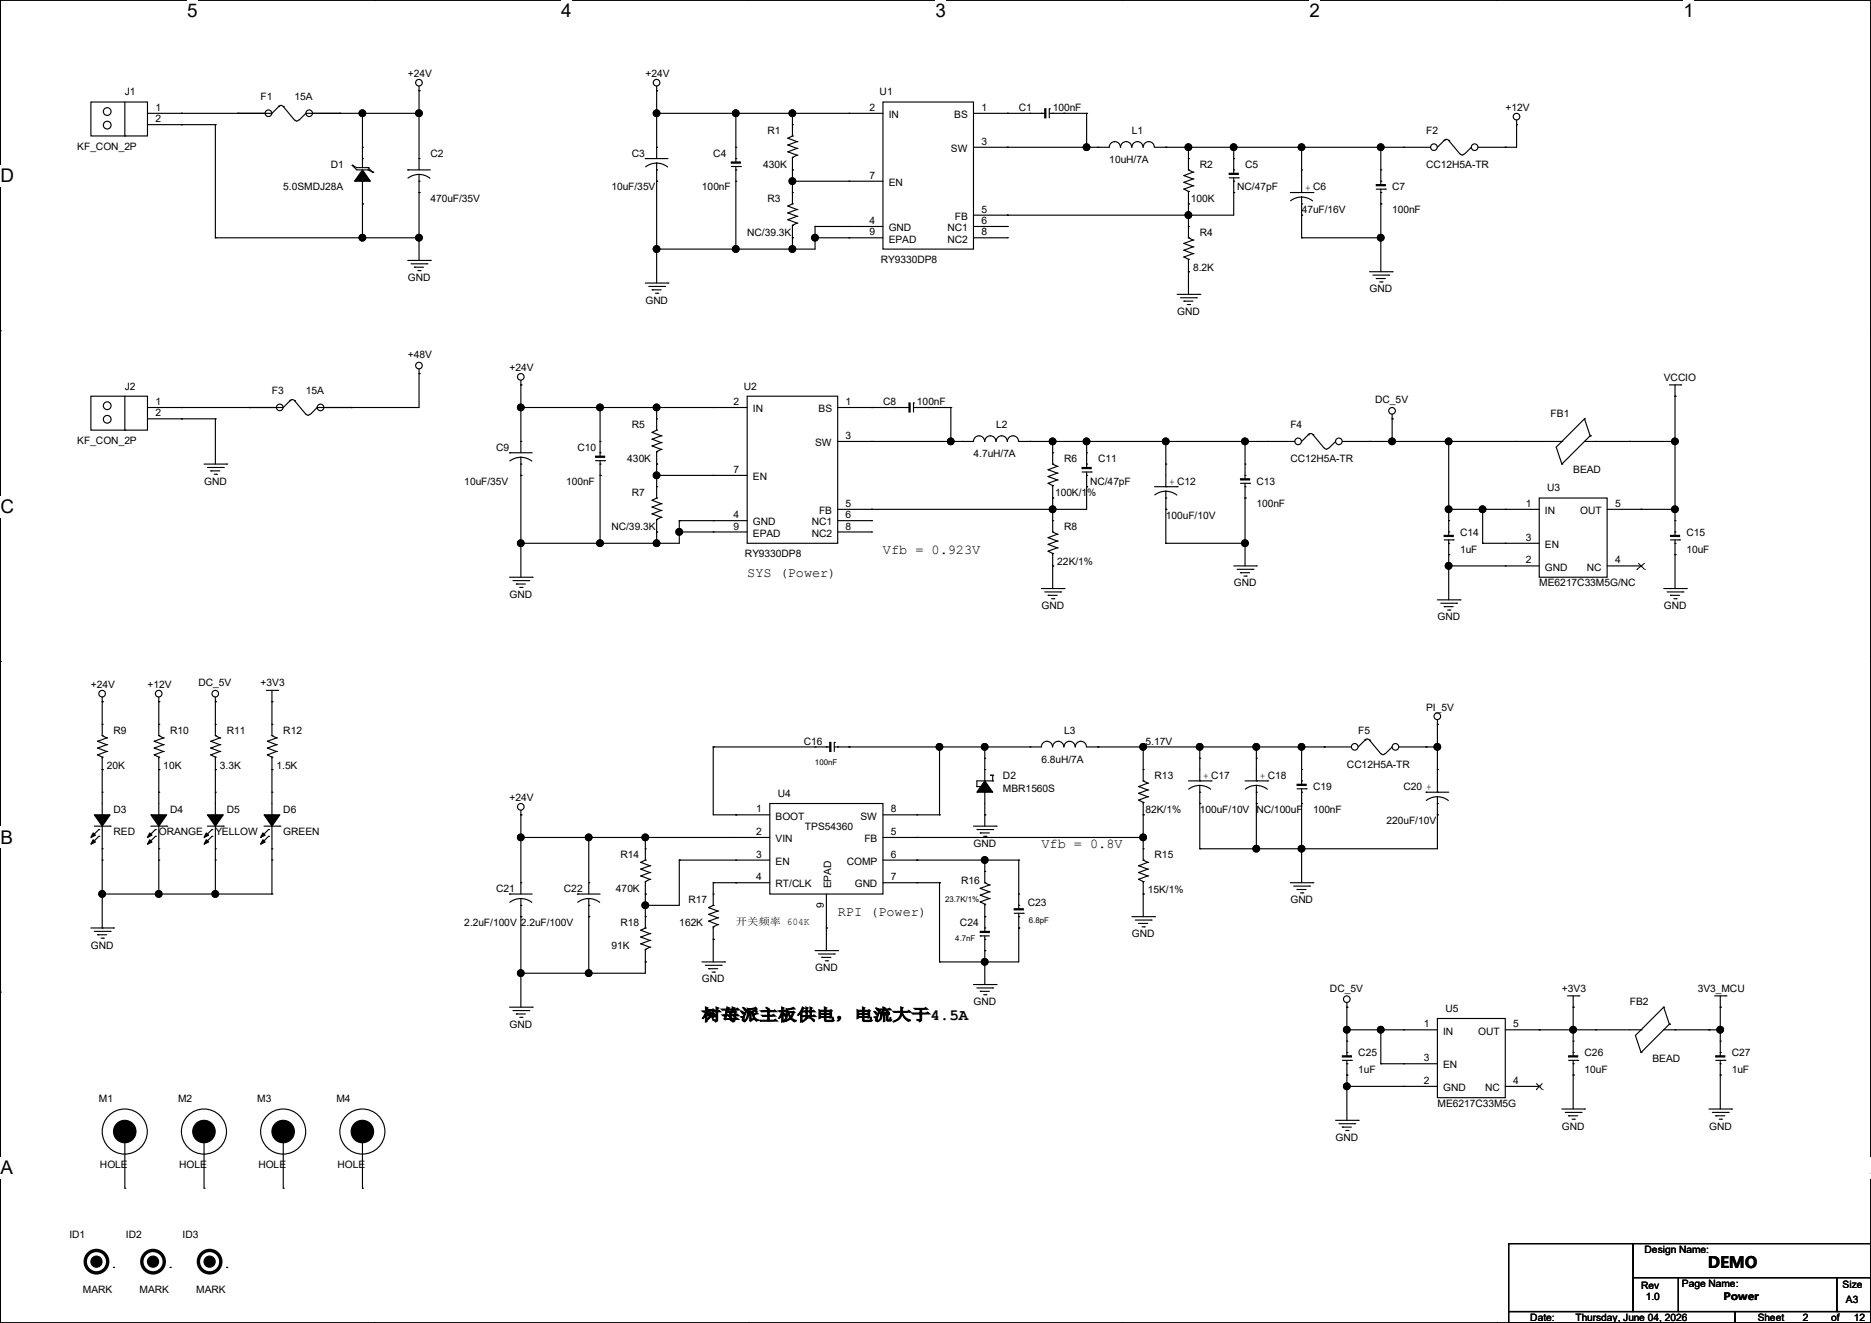
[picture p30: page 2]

5

4

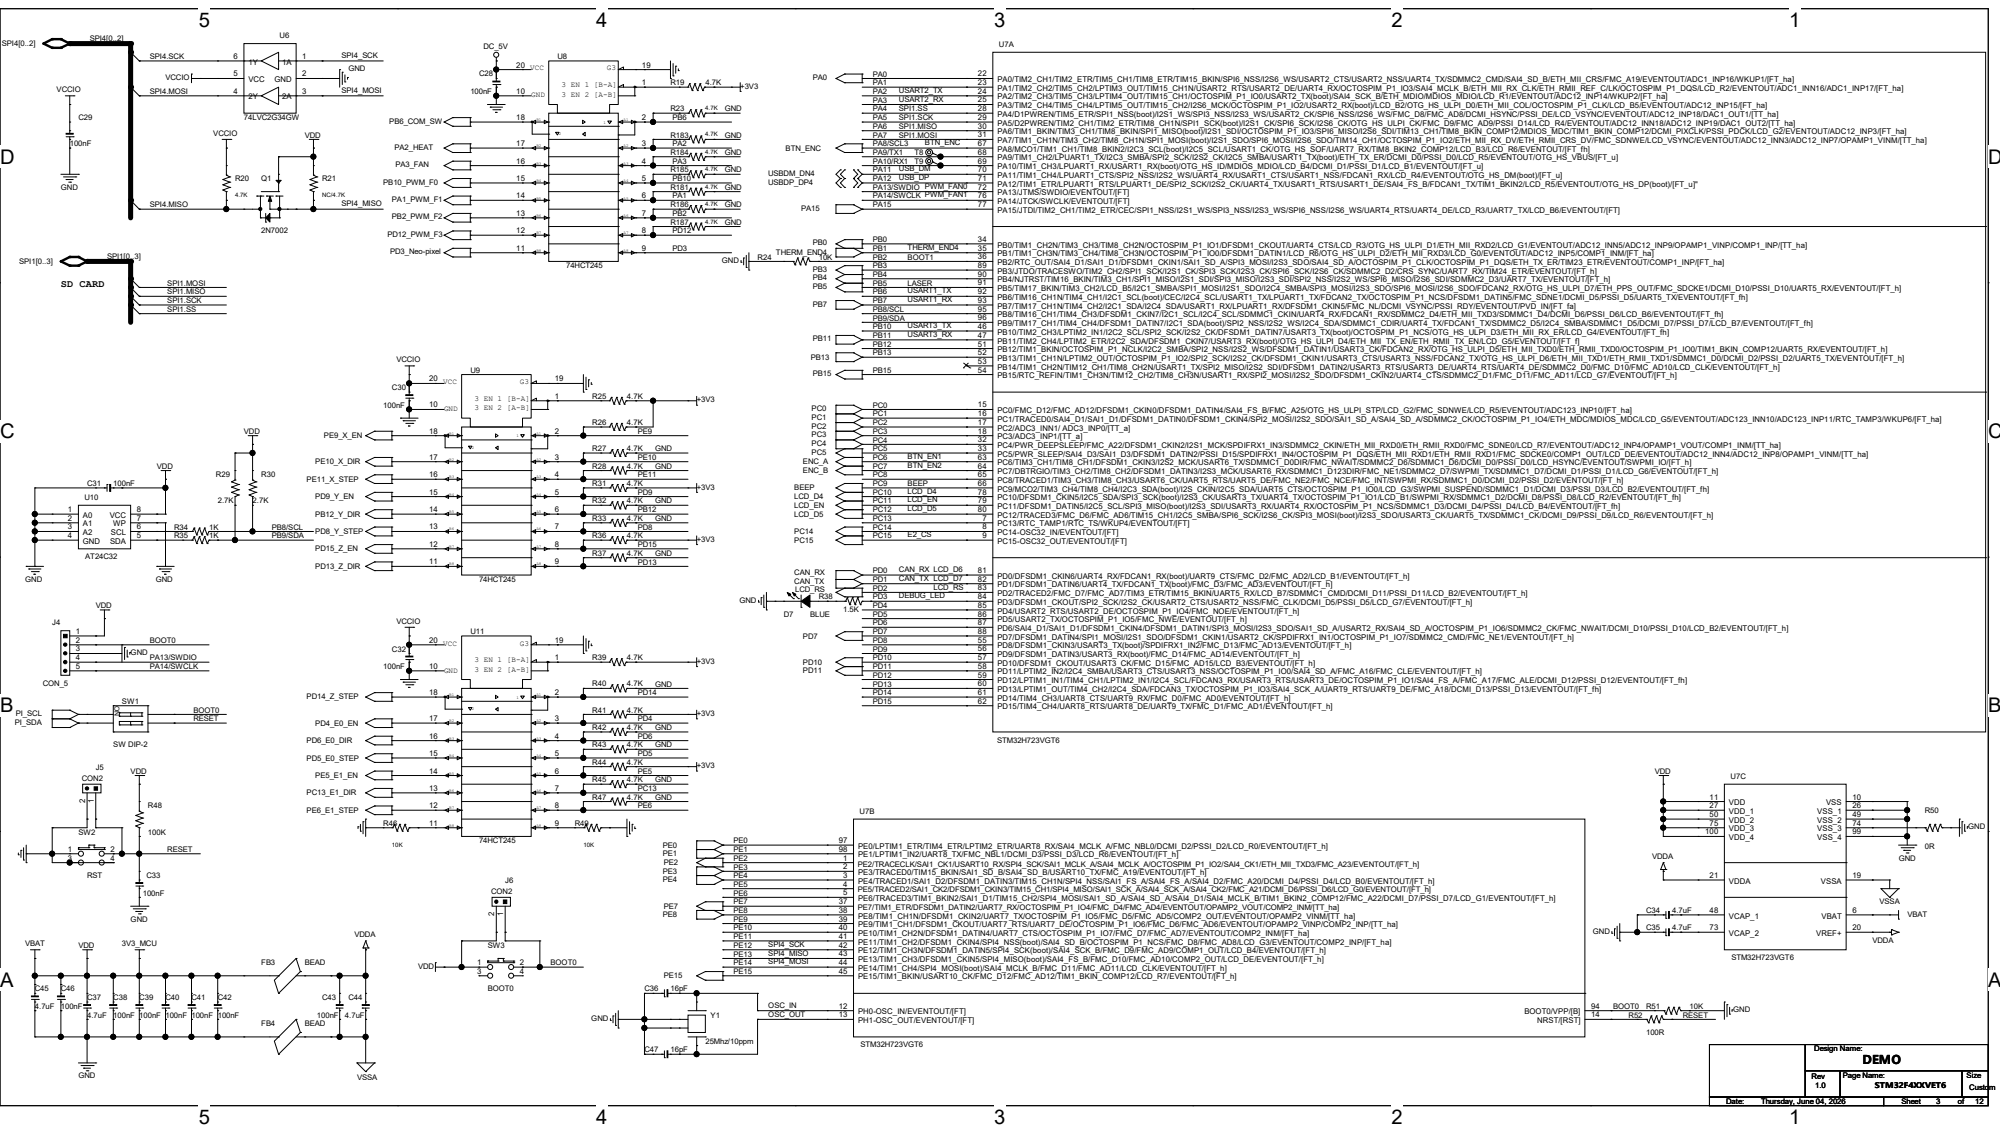
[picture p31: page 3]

PA9/TIM1_CH2/LPUART1_TX/I2C3_SMBA/SPI2_SCK/I2S2_CK/I2C5_SMBA/USART1_TX(boot)/ETH_TX_ER/DCMI_D0/PSSI_D0/LCD_R5/EVENTOUT/OTG_HS_VBUS/[FT_u] 68
PA10/TIM1_CH3/LPUART1_RX/USART1_RX(boot)/OTG_HS_ID/MDIOS_MDIO/LCD_B4/DCMI_D1/PSSI_D1/LCD_B1/EVENTOUT/[FT_u] 69
PA11/TIM1_CH4/LPUART1_CTS/SPI2_NSS/I2S2_WS/UART4_RX/USART1_CTS/USART1_NSS/FDCAN1_RX/LCD_R4/EVENTOUT/OTG_HS_DM(boot)/[FT_u] 70
PA12/TIM1_ETR/LPUART1_RTS/LPUART1_DE/SPI2_SCK/I2S2_CK/UART4_TX/USART1_RTS/USART1_DE/SAI4_FS_B/FDCAN1_TX/TIM1_BKIN2/LCD_R5/EVENTOUT/OTG_HS_DP(boot)/[FT_u]" 71
PA13/JTMS/SWDIO/EVENTOUT/[FT] 72
PA14/JTCK/SWCLK/EVENTOUT/[FT] 76
PA15/JTDI/TIM2_CH1/TIM2_ETR/CEC/SPI1_NSS/I2S1_WS/SPI3_NSS/I2S3_WS/SPI6_NSS/I2S6_WS/UART4_RTS/UART4_DE/LCD_R3/UART7_TX/LCD_B6/EVENTOUT/[FT] 77

D D

# (Iset=60K/Rset\) ,Rset不小于22K。

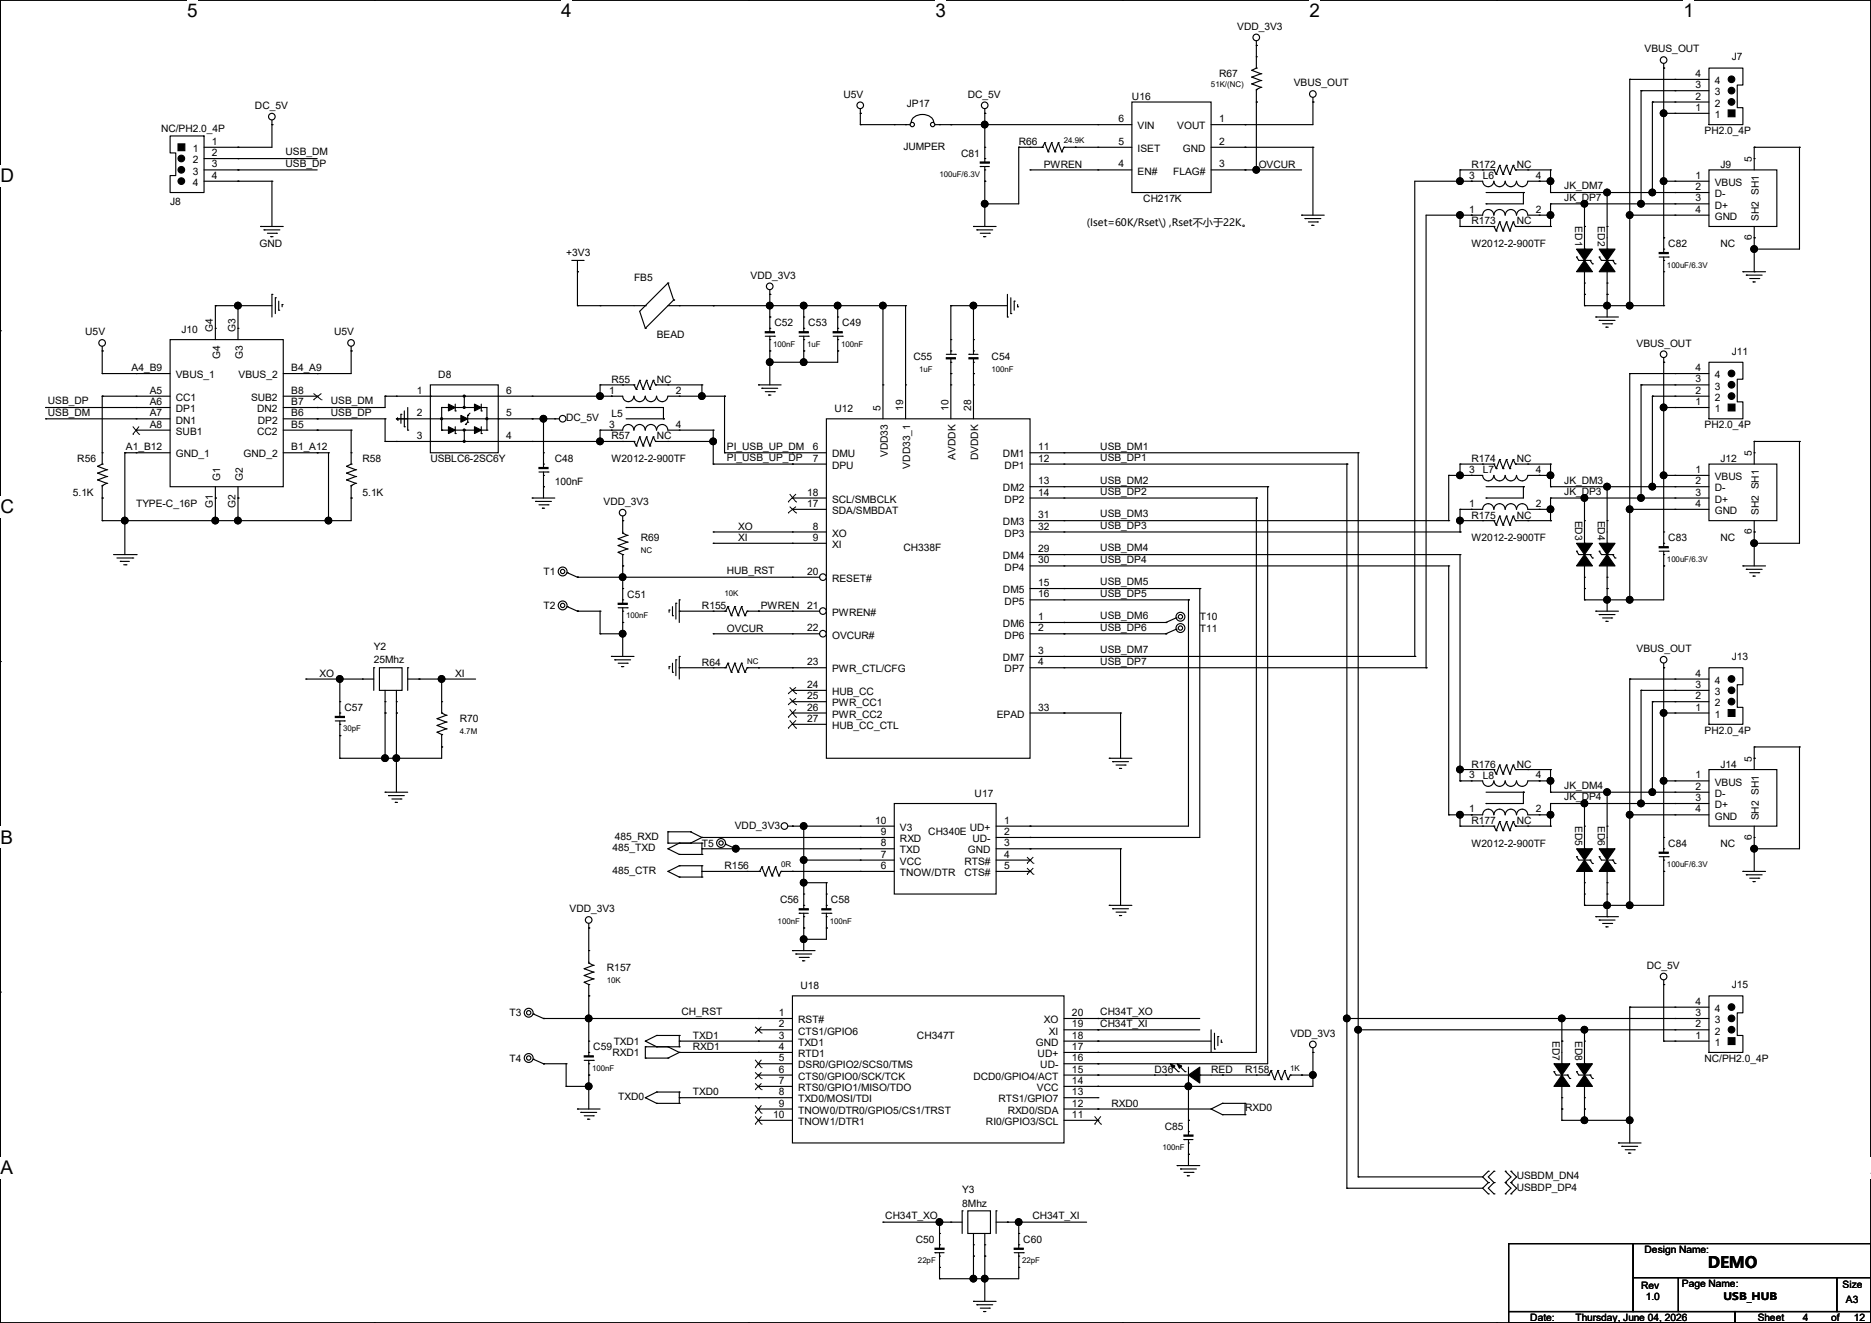
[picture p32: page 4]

SDA/SMBDAT 17 SCL/SMBCLK 18

CTS# 5 TNOW/DTR 6 VCC 7 TXD 8 RXD 9 V3 10

D D

HEAT | FAN

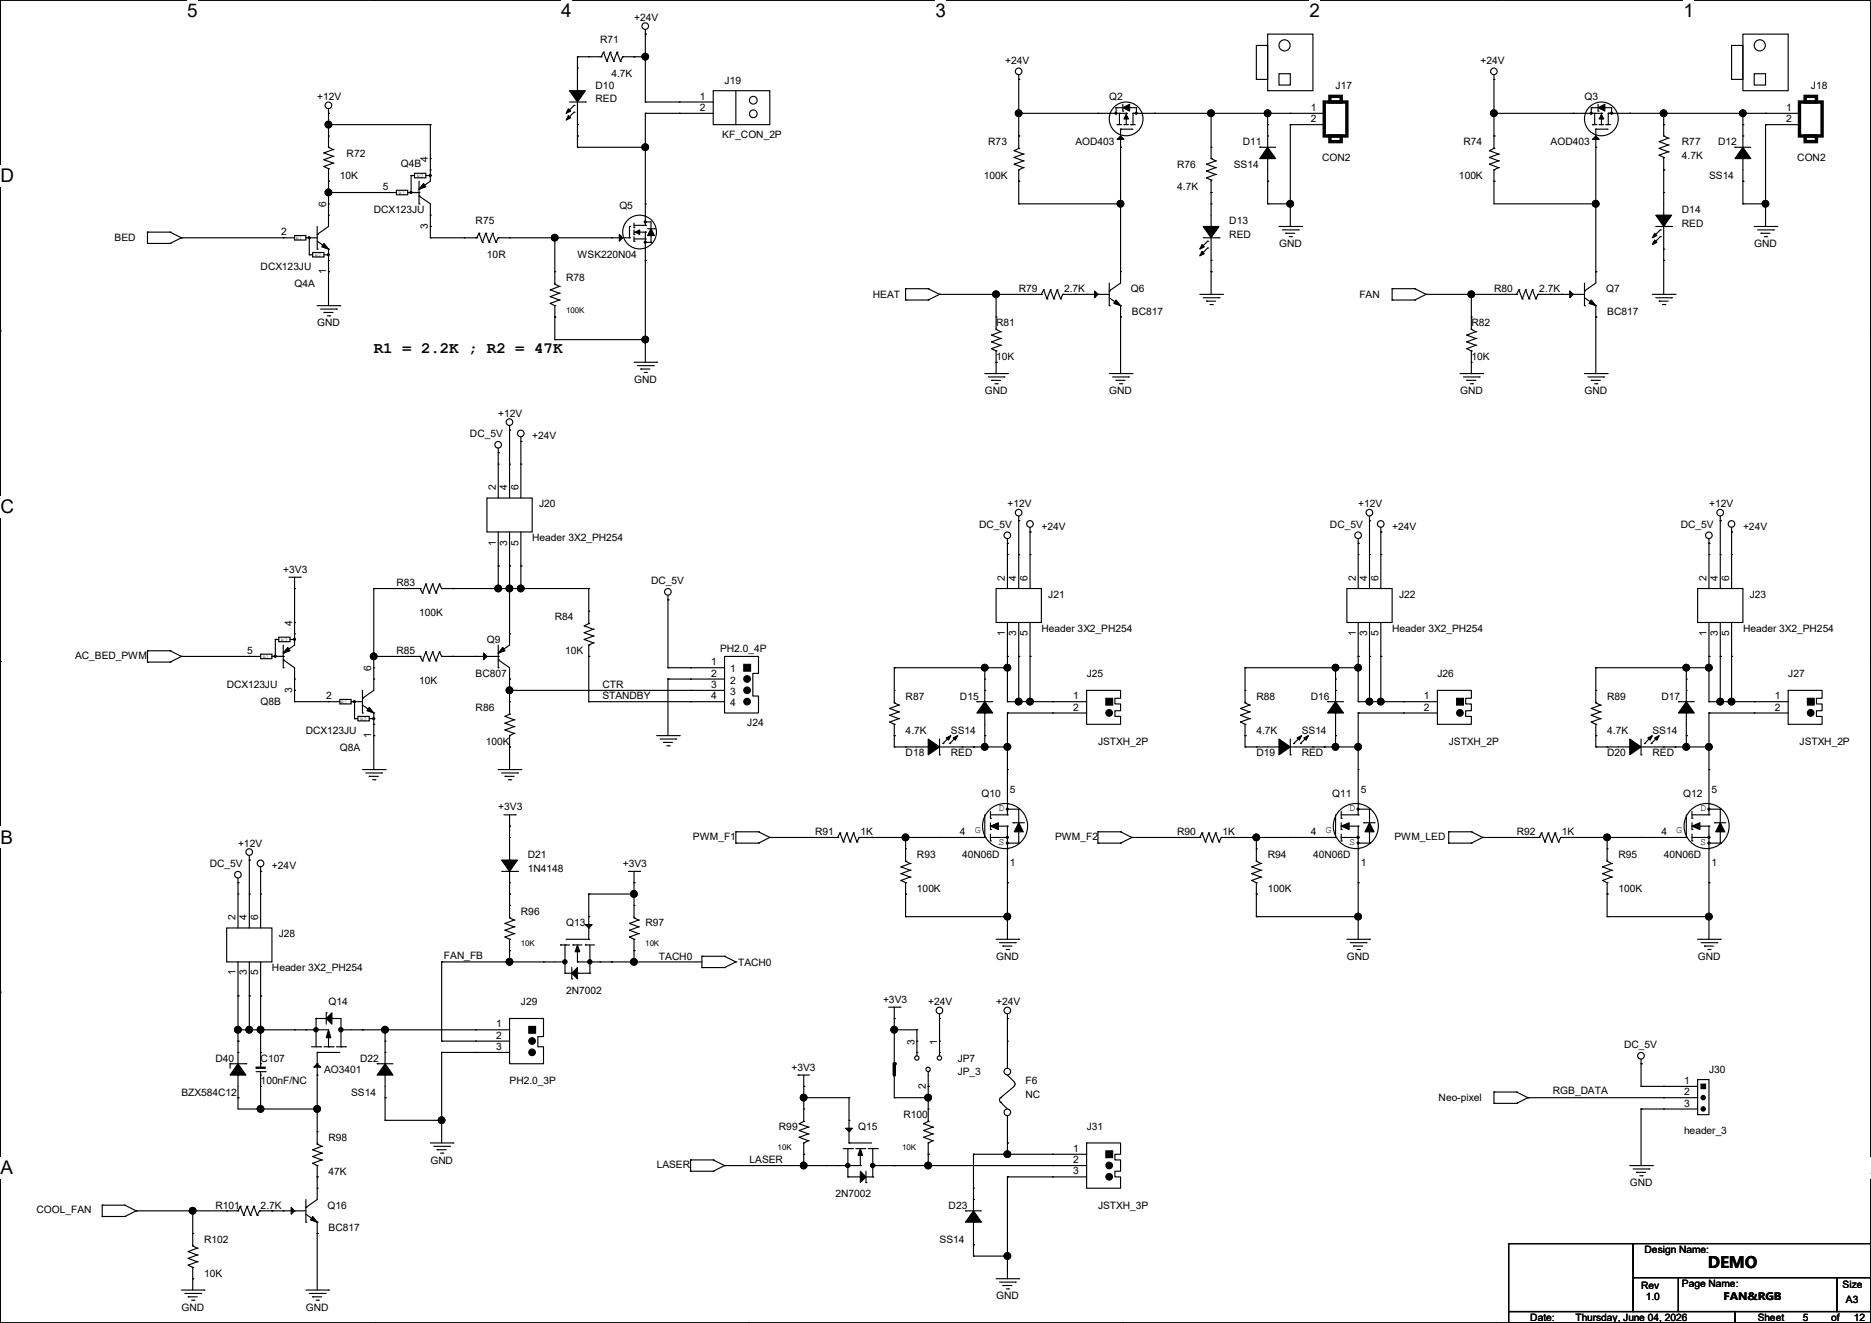
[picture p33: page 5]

D D

## SPI1[0..3]

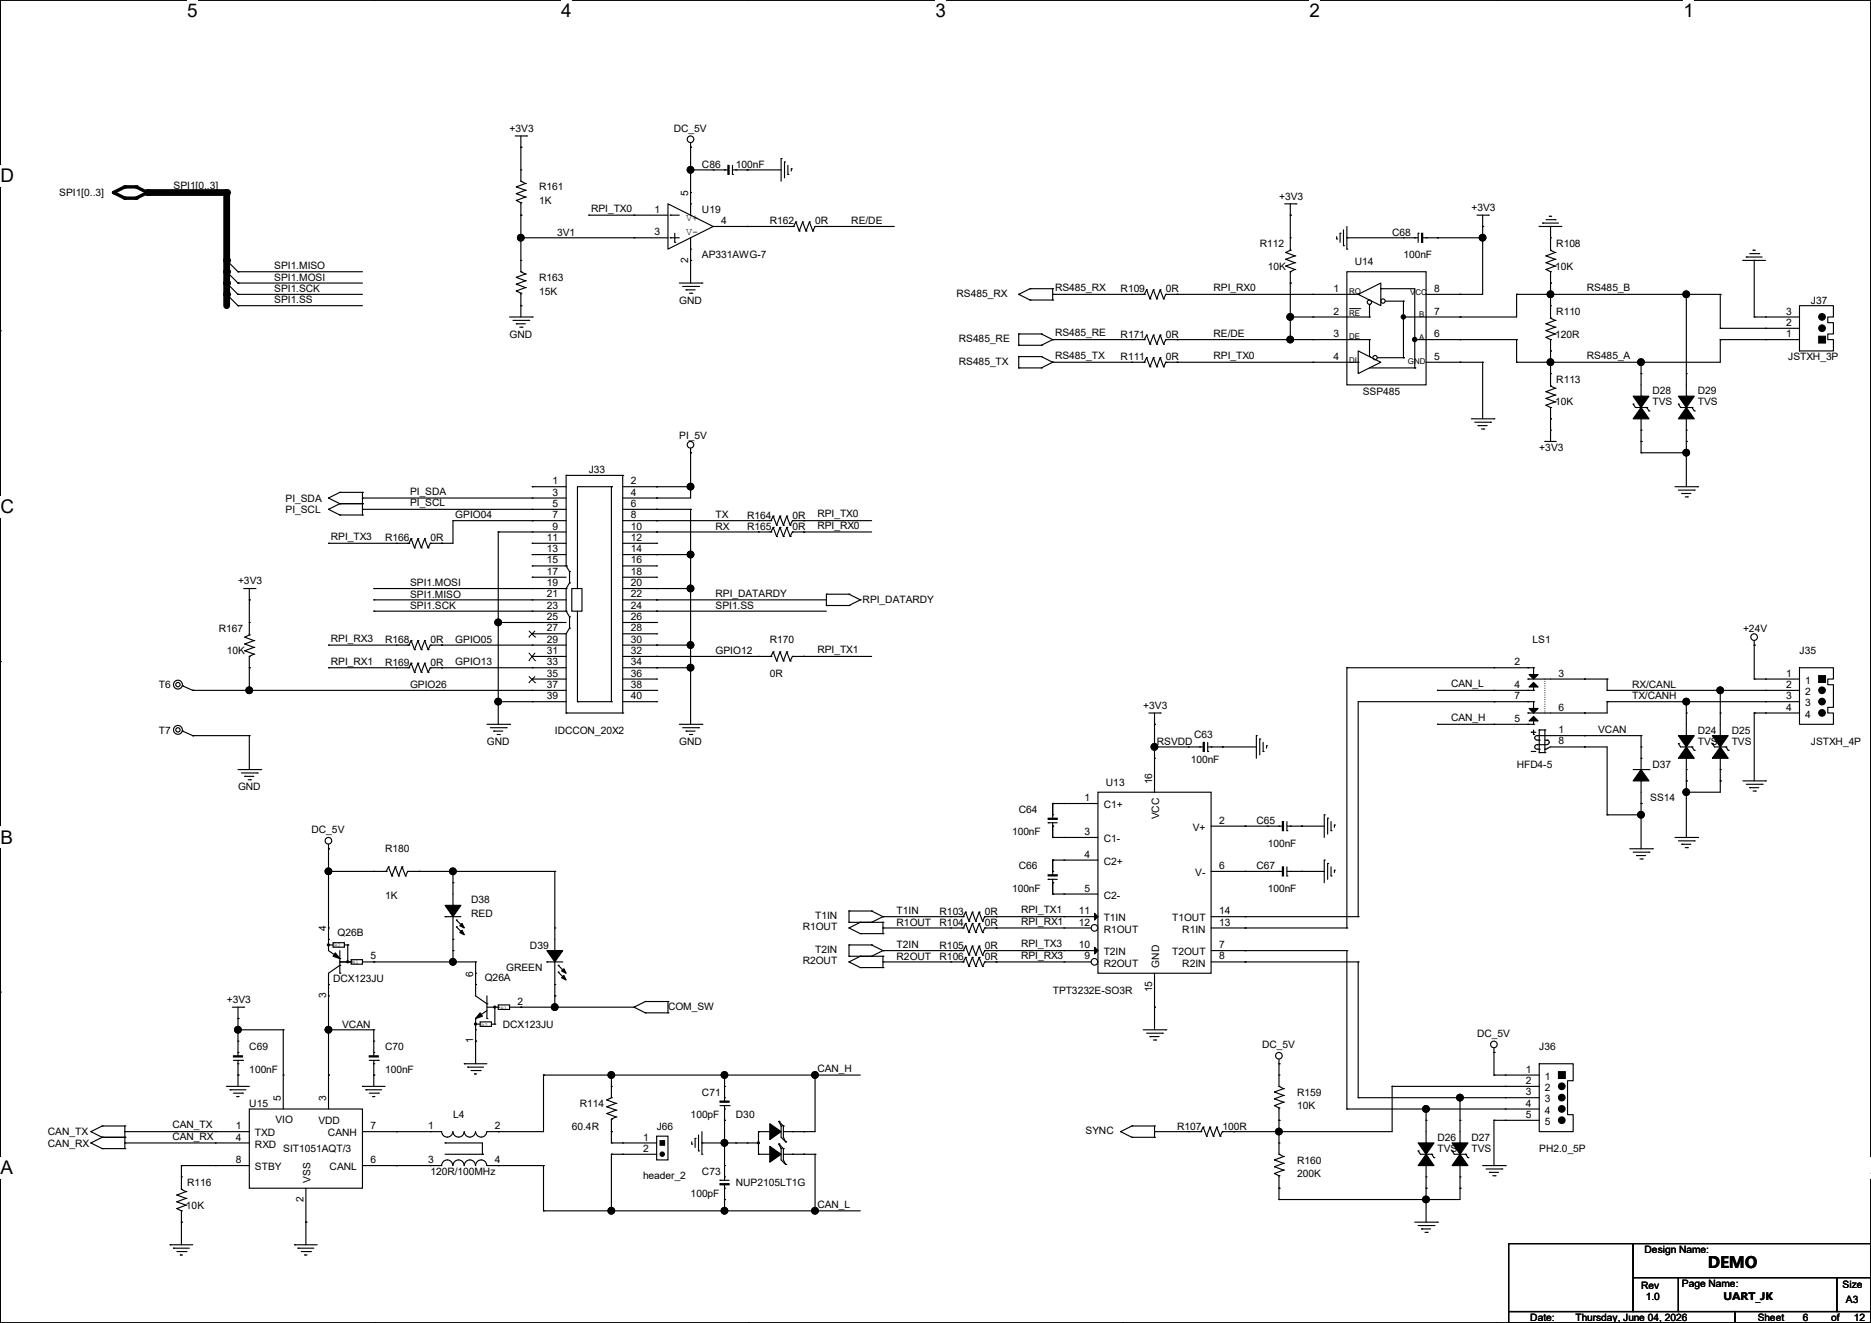
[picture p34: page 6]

D D

E0

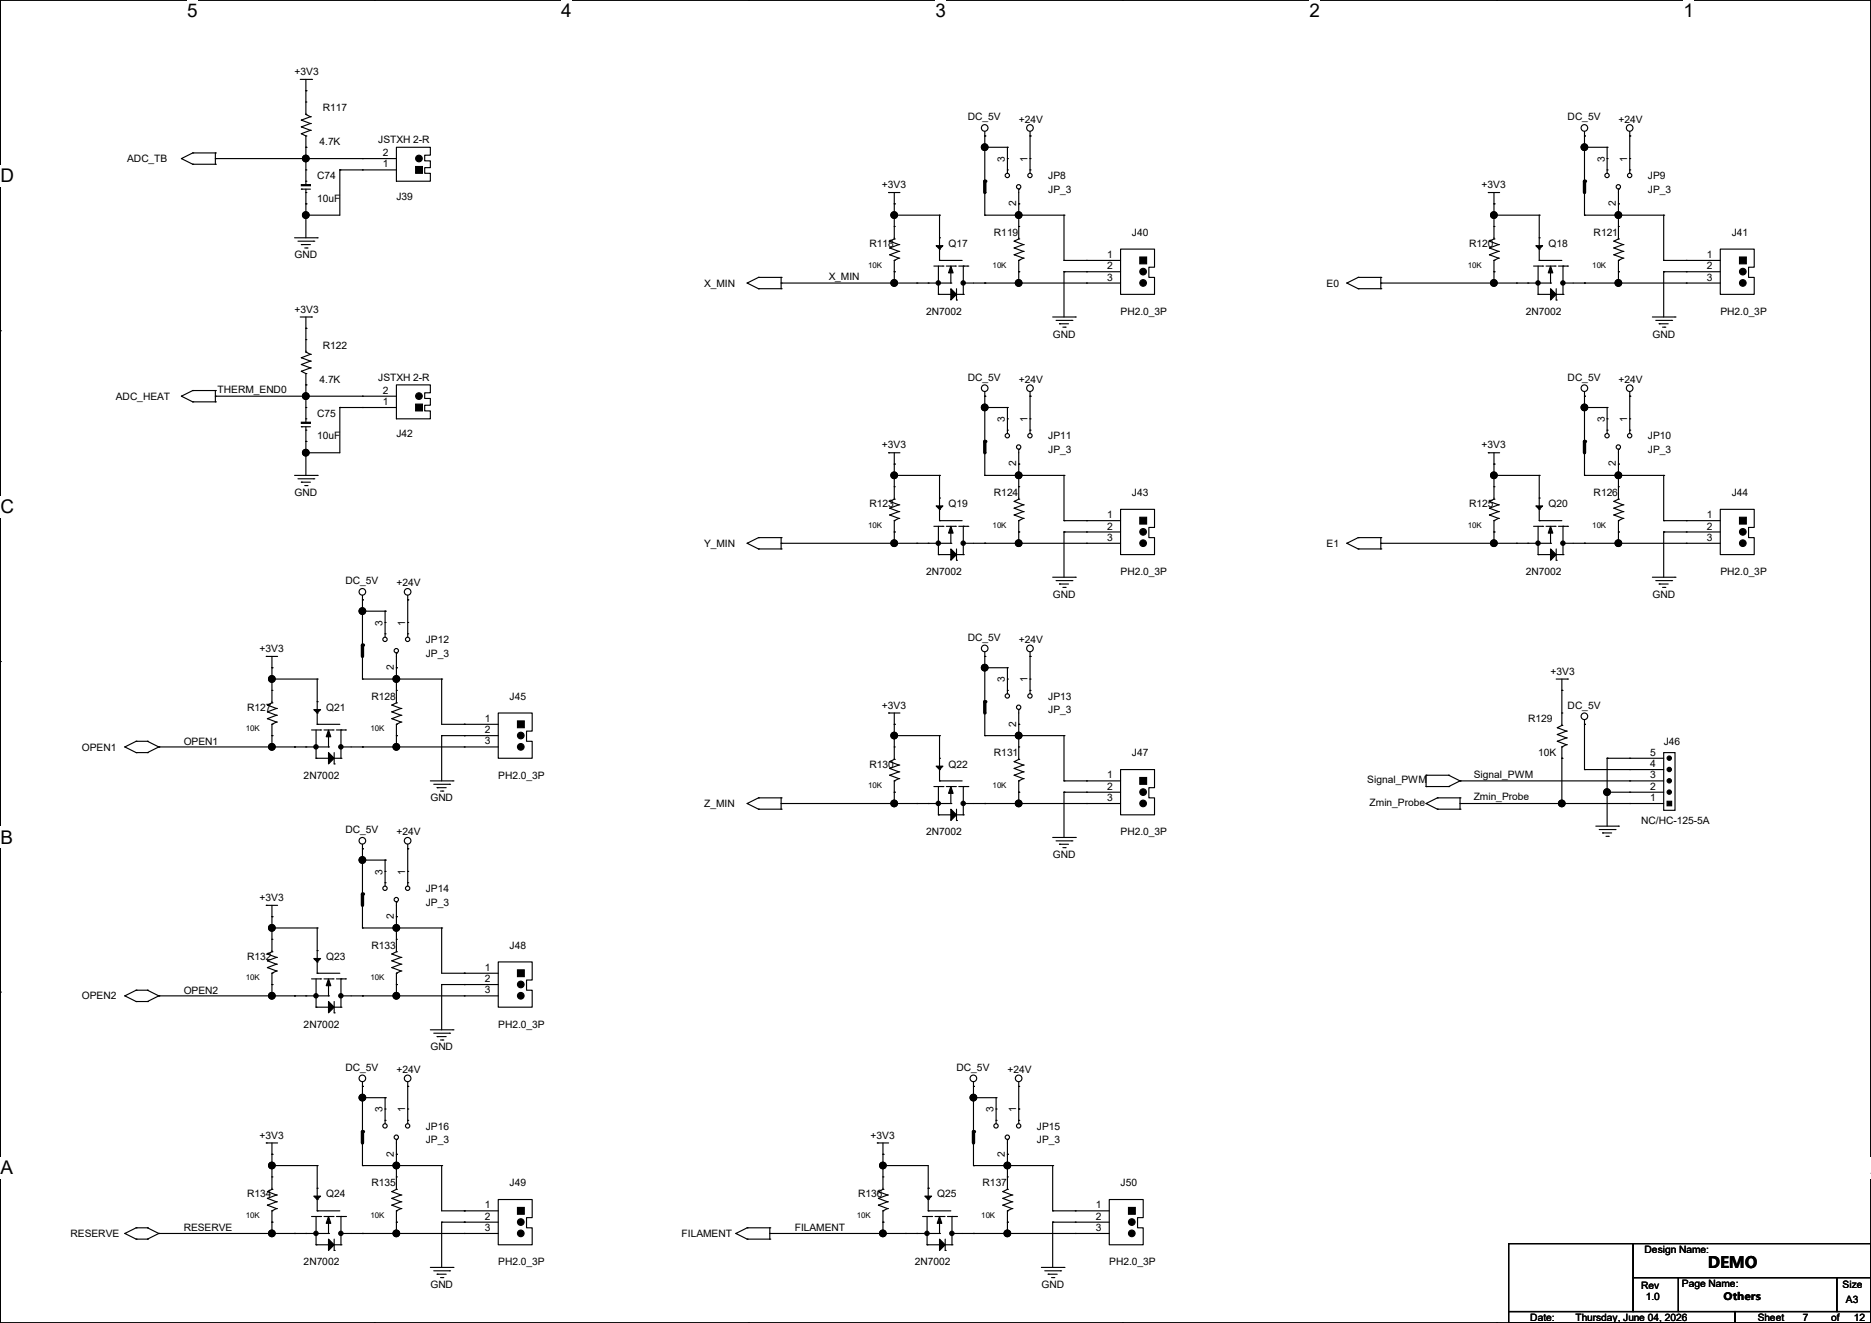
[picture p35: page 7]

D D

+48V

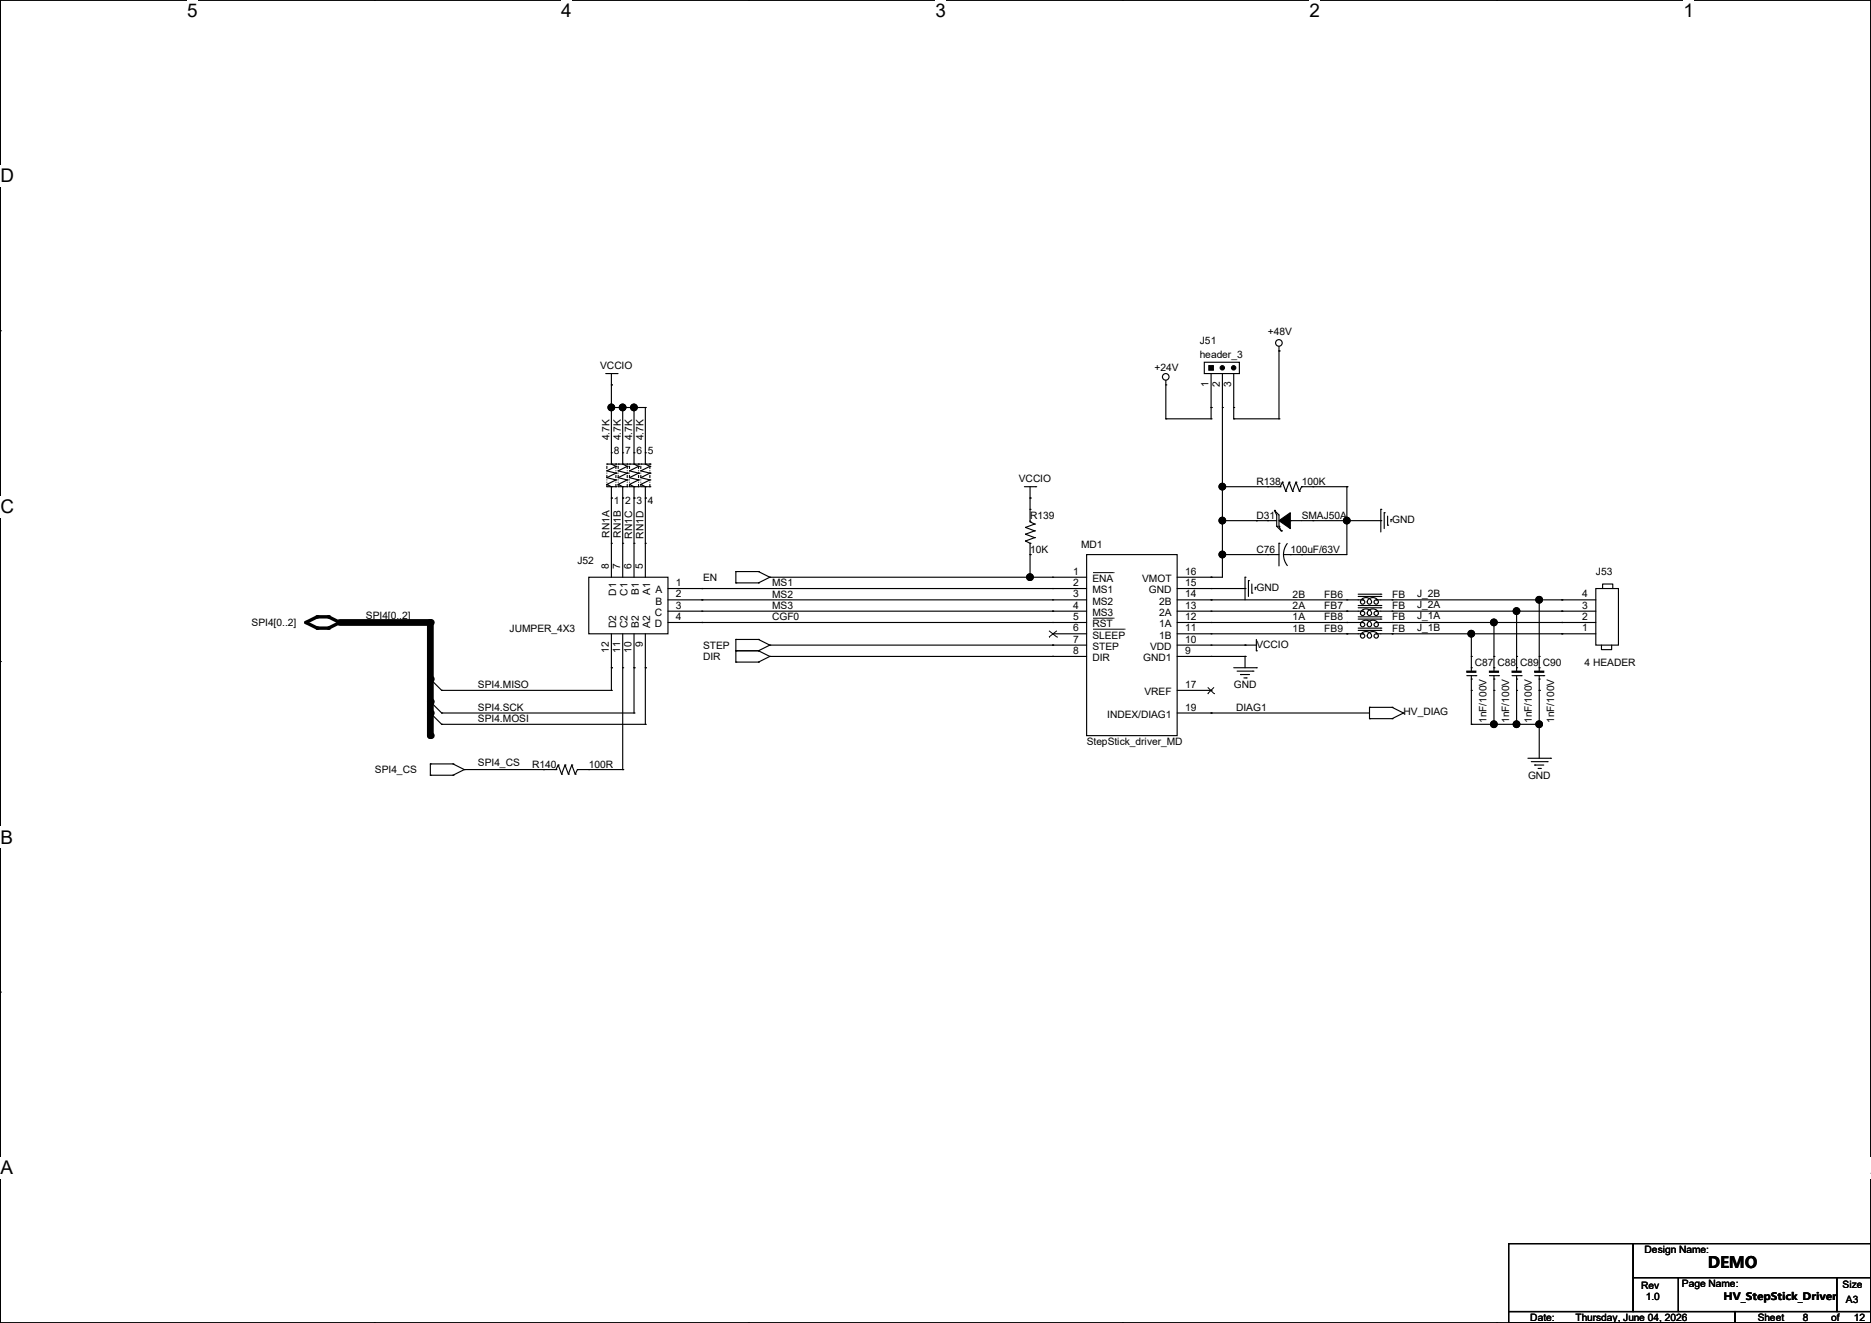
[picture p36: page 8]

D D

+48V

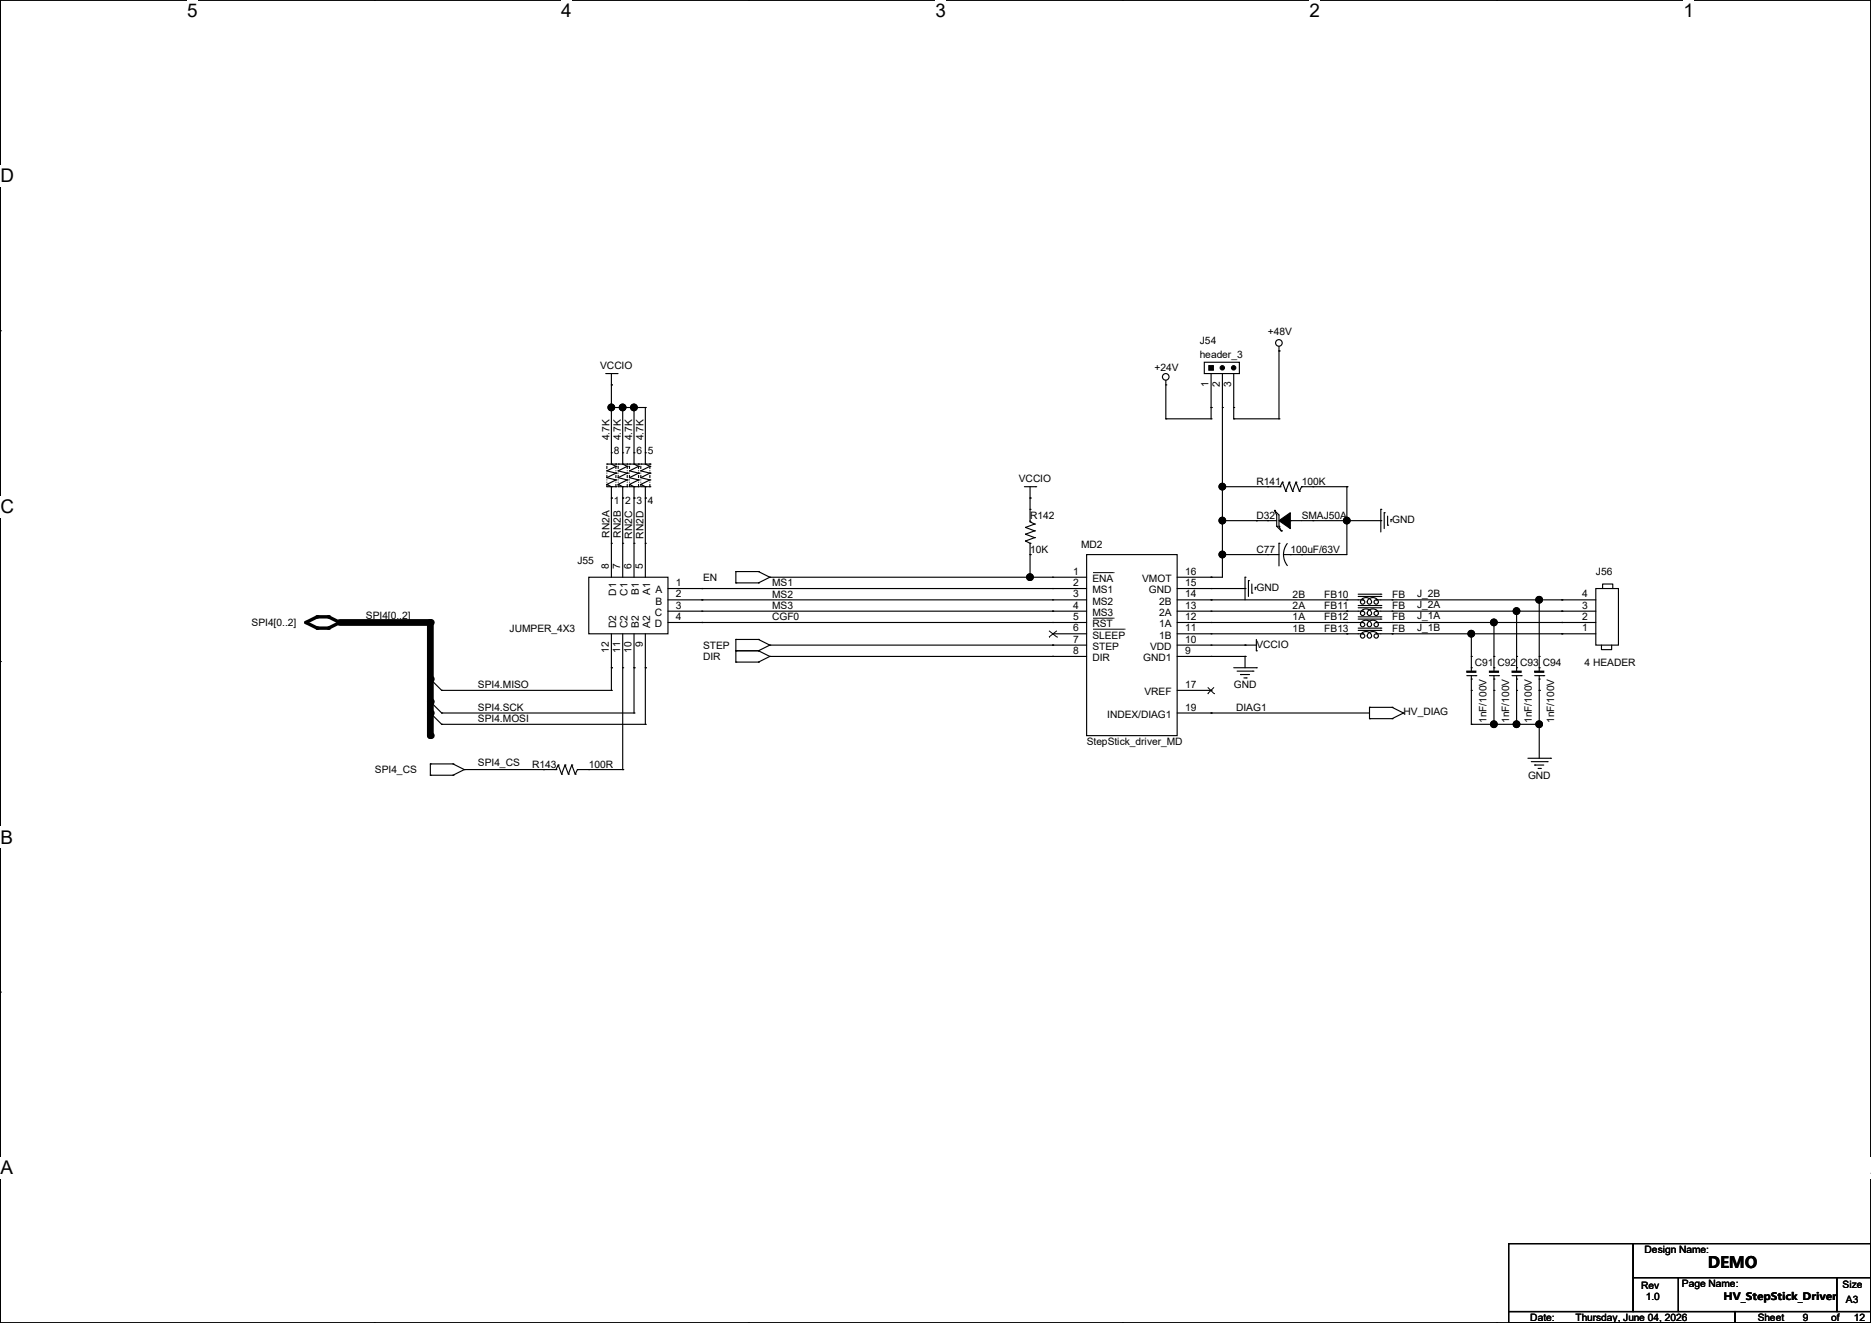
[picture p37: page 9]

D D

+48V

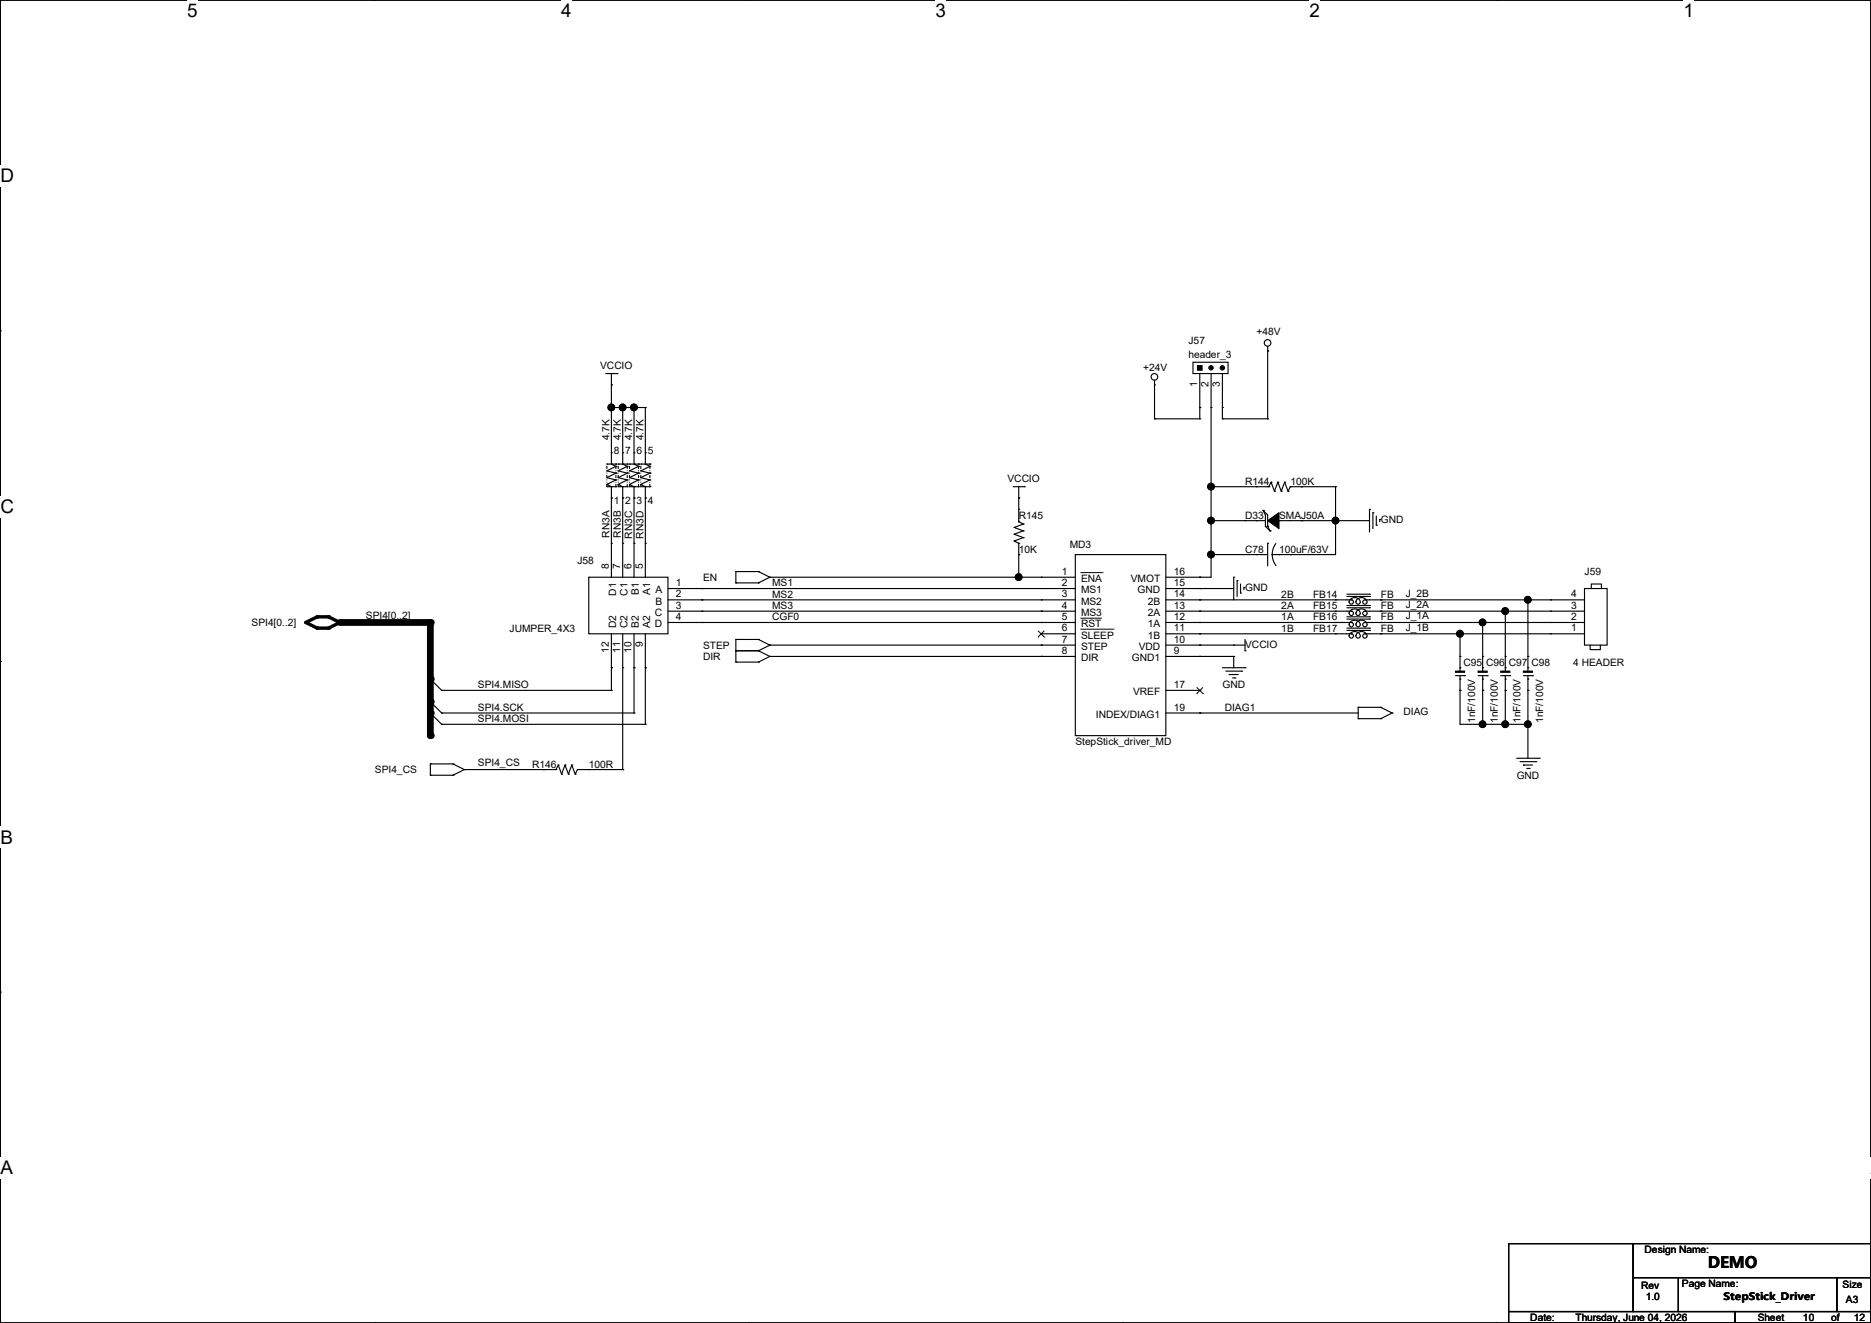
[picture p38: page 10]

D D

+48V

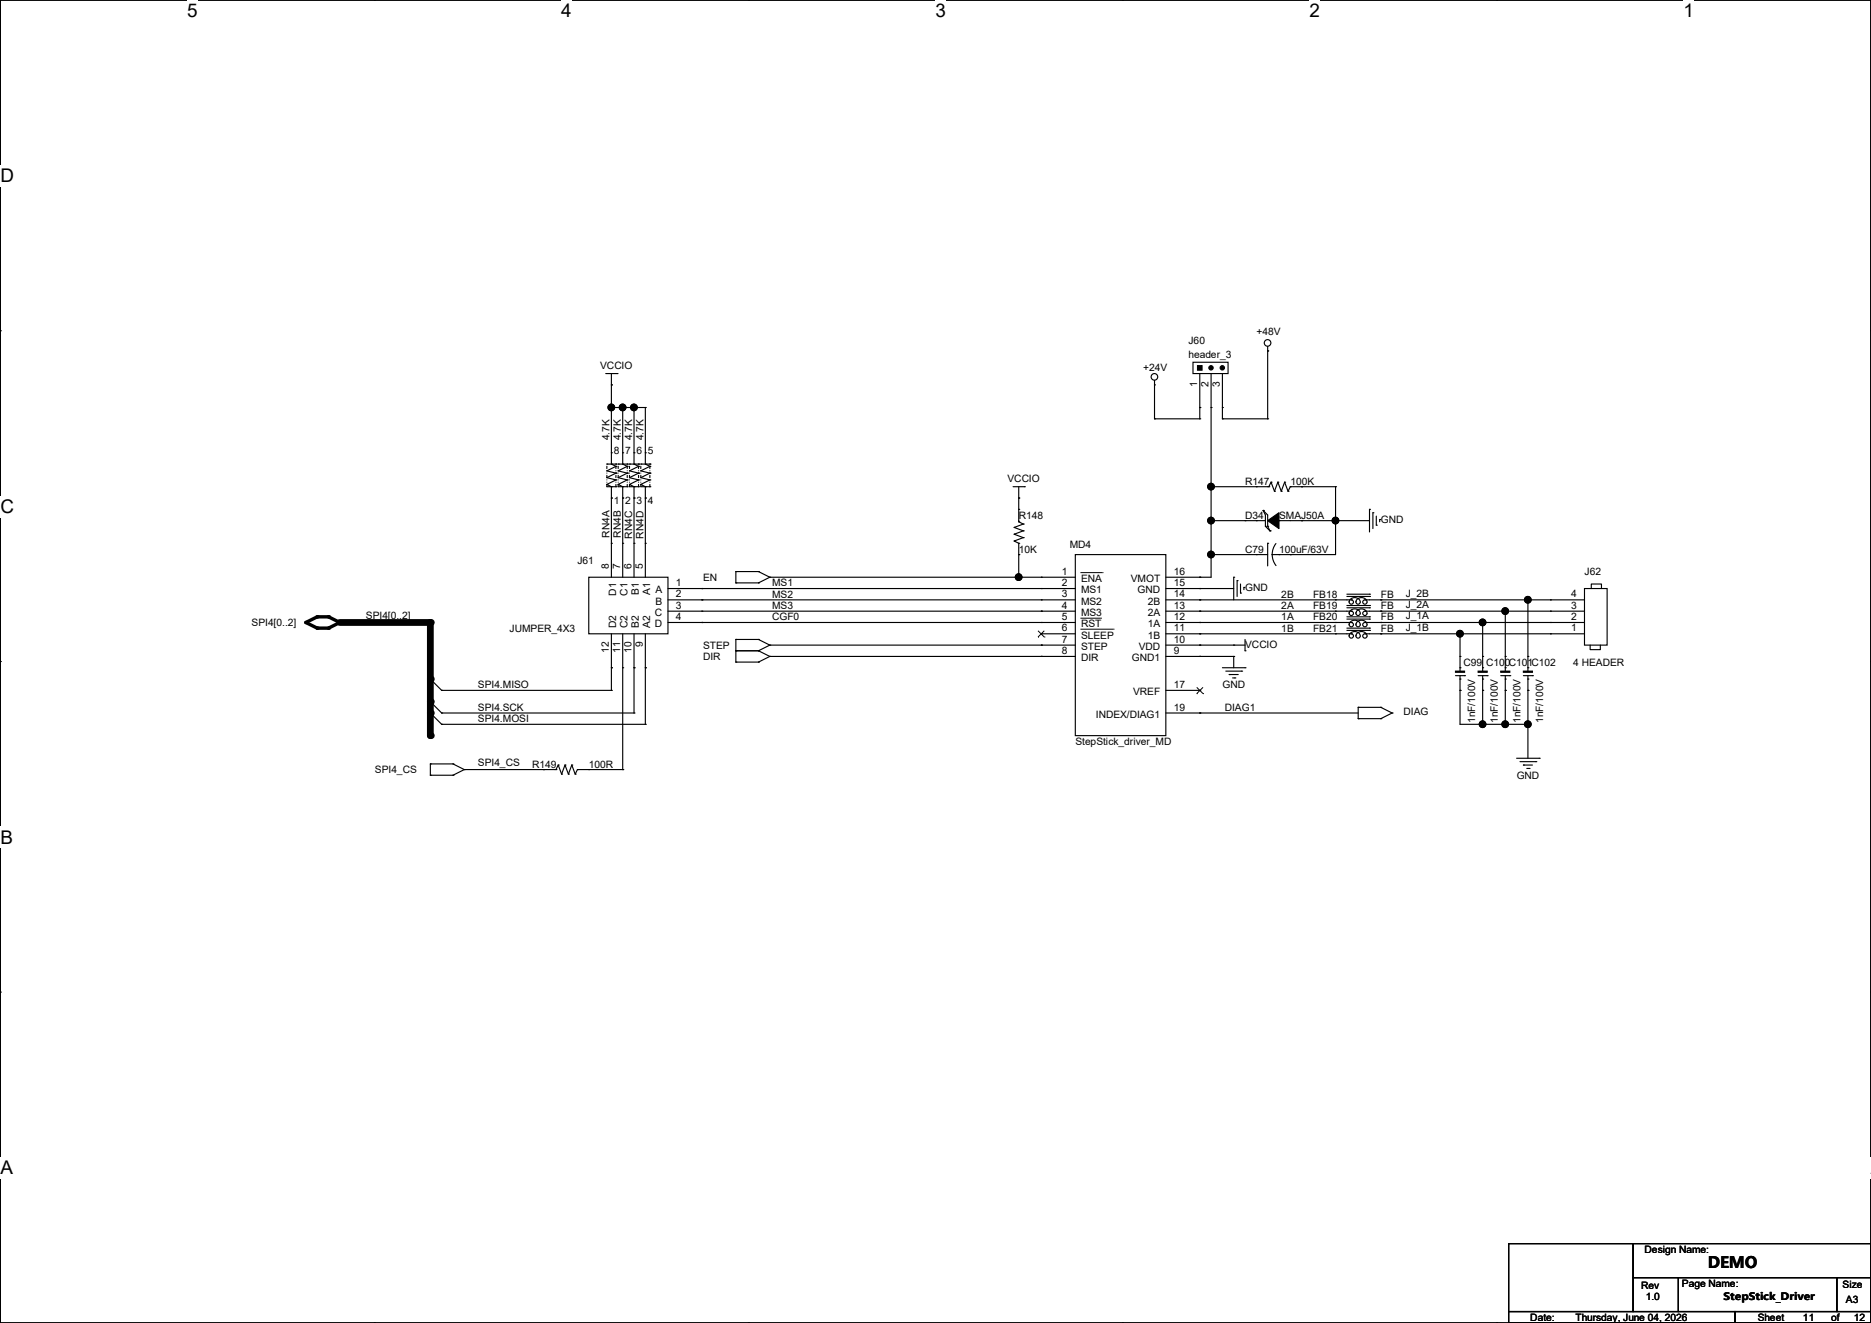
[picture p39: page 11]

D D

+48V

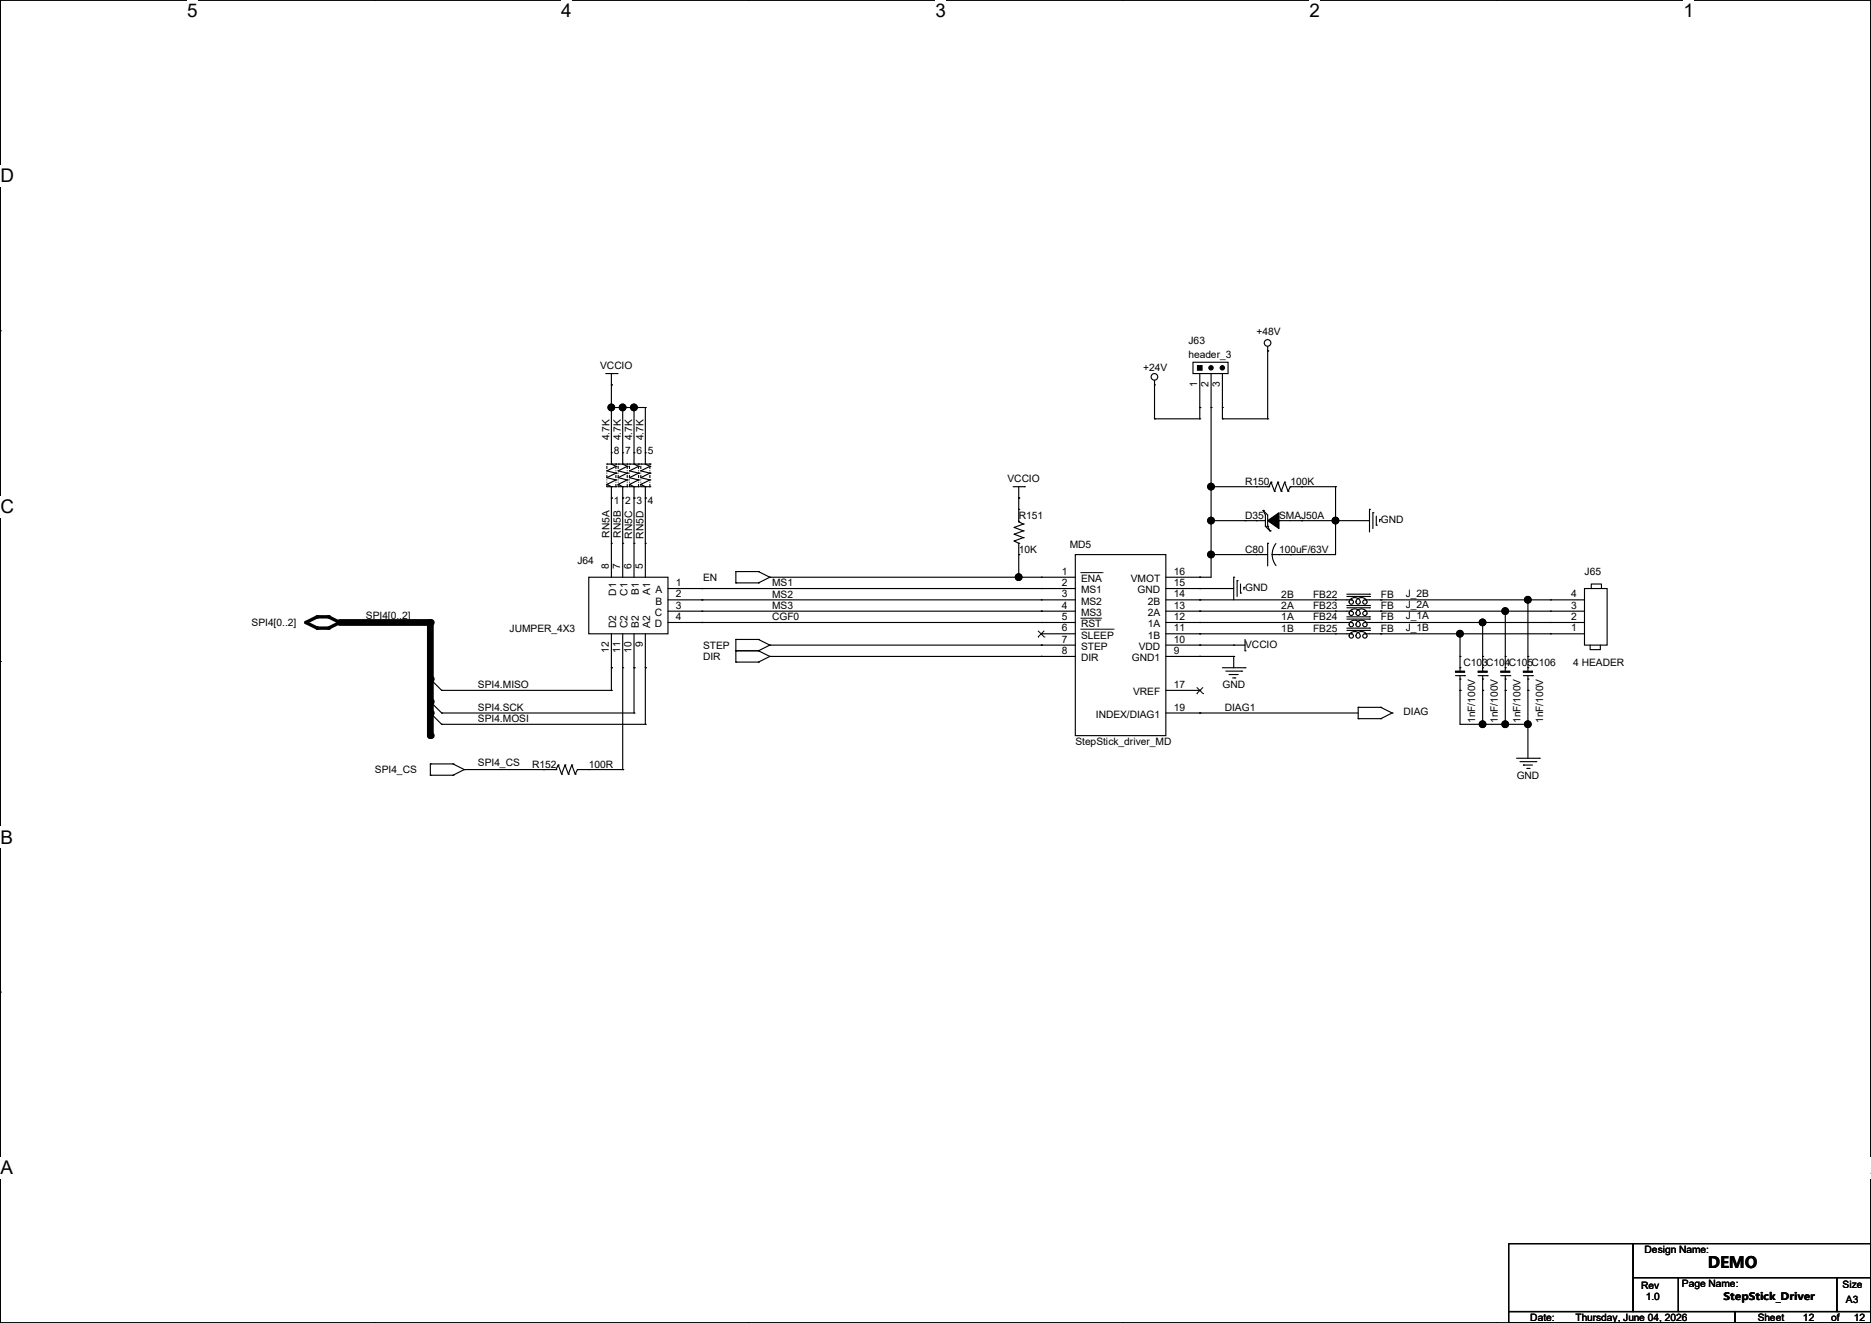
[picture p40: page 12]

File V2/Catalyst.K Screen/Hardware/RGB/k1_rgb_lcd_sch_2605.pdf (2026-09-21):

5 | 4 | 3 | 2 | 1

D D


The best choice for R53
is 2.0K precision resistance.

5 | 4 | 3 | 2 | 1

D D


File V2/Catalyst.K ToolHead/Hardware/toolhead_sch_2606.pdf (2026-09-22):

5 | 4 | 3 | 2 | 1

D D

Design Name:; Rev; Page Name:; Size; Date:; Sheet; DEMO; Friday, April 10, 2026; Block_Diagram; IN_Power; P01_IN_Power; T1IN R1OUT; USB_DP; USB_DM; COM_SW; MCU; P02_MCU; PA13_DIAG; PA9_USART1_TX PA10_USART1_RX; PA11_DM/CAN_RX PA12_DP/CAN_TX; PC15_HEAT_PWM; PA4_PWM PA3_PWM; PB10_PWM; PA8_FAN1_FG; PC13_PWM; PB6_DIR; PB7_STEP; PA15_PDN_UART; PB5_PWM; StepStick_Driver; P03_StepStick_Driver; ENN STEP DIR; PDN_UART DIAG; Other; P04_Other; FAN0_FG; Signal_PWM Zmin_Probe; FAN3_PWM; FAN2_PWM; FAN1_PWM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

D D

## Vre = 0.596V


D D


D D


D D

## 加热棒


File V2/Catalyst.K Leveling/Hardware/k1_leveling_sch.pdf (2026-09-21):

5 | 4 | 3 | 2 | 1

D D


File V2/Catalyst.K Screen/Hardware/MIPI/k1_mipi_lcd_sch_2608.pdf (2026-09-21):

5 | 4 | 3 | 2 | 1

D D


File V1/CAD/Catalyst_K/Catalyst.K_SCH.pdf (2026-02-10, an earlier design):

5

4

VMOT; USB_Type-C; Design Name:; Rev; Page Name:; Size; Date:; Sheet; DEMO; Monday, December 29, 2025; Block_Diagram; P04_UART_JK; CAN_TX CAN_RX; SPI1[0..3]; PI_SCL PI_SDA; R1OUT; R2OUT; SYNC; RPI_DATARDY; StepStick_Driver_E1; P07_StepStick_Driver; STEP; DIR; SPI4_CS; DIAG; SPI4[0..2]; P05_Others; X_MIN Y_MIN Z_MIN; OPEN2; FILAMENT; Zmin_Probe; OPEN1; Signal_PWM; RESERVE; ADC_TB ADC_HEAT; P01_Power; StepStick_Driver_Z; HV_StepStick_Driver_X; P06_HV_StepStick_Driver; HV_DIAG; EN STEP DIR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

5 | 4 | 3 | 2 | 1

D D


5

4


PA9/TIM1_CH2/LPUART1_TX/I2C3_SMBA/SPI2_SCK/I2S2_CK/I2C5_SMBA/USART1_TX(boot)/ETH_TX_ER/DCMI_D0/PSSI_D0/LCD_R5/EVENTOUT/OTG_HS_VBUS/[FT_u] 68
PA10/TIM1_CH3/LPUART1_RX/USART1_RX(boot)/OTG_HS_ID/MDIOS_MDIO/LCD_B4/DCMI_D1/PSSI_D1/LCD_B1/EVENTOUT/[FT_u] 69
PA11/TIM1_CH4/LPUART1_CTS/SPI2_NSS/I2S2_WS/UART4_RX/USART1_CTS/USART1_NSS/FDCAN1_RX/LCD_R4/EVENTOUT/OTG_HS_DM(boot)/[FT_u] 70
PA12/TIM1_ETR/LPUART1_RTS/LPUART1_DE/SPI2_SCK/I2S2_CK/UART4_TX/USART1_RTS/USART1_DE/SAI4_FS_B/FDCAN1_TX/TIM1_BKIN2/LCD_R5/EVENTOUT/OTG_HS_DP(boot)/[FT_u]" 71
PA13/JTMS/SWDIO/EVENTOUT/[FT] 72
PA14/JTCK/SWCLK/EVENTOUT/[FT] 76
PA15/JTDI/TIM2_CH1/TIM2_ETR/CEC/SPI1_NSS/I2S1_WS/SPI3_NSS/I2S3_WS/SPI6_NSS/I2S6_WS/UART4_RTS/UART4_DE/LCD_R3/UART7_TX/LCD_B6/EVENTOUT/[FT] 77

D D

# (Iset=60K/Rset\) ,Rset不小于22K。


SDA/SMBDAT 17 SCL/SMBCLK 18

CTS# 5 TNOW/DTR 6 VCC 7 TXD 8 RXD 9 V3 10

D D

HEAT | FAN


D D

## SPI1[0..3]


D D

E0


D D

+48V


D D

+48V


D D

+48V


D D

+48V


D D

+48V


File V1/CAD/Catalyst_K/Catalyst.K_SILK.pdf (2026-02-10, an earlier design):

# ART FILM - adt

3V3


# ART FILM - adb

# 24V PC5 PC15 PD11

GND; VLED; PE0JP8 GND; STDBY; COM; 48V²⁴ GND; PROBE; PWM; MOT-E1; DIAG:PD12; SC/PDN:PC14; STEP:PE6; DIR:PC13; MOT-E0; DIAG:PC4; SC/PDN:PD7; STEP:PD5; DIR:PD6; SC/PDN:PE7; MOT_SPI4; MOT-X; DIAG:PE0; DIR:PE10; STEP:PE11; SCK:PE12; MISO:PE13; MOSI:PE14; DIAG:PB13; SC/PDN:PE15; MOT-Y; DIR:PB12; STEP:PD8; SC/PDN:PD10; MOT-Z; DIAG:PE1; DIR:PD13; STEP:PD14; SYNC; BOOT0; RST; CANL; CANH

ART FILM - adb

# ART FILM - silktop

3V3


# ART FILM - silkbotm

# 24V PC5 PC15 PD11

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

ART FILM - silkbotm

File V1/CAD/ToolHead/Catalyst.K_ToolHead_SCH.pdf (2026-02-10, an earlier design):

5 | 4 | 3 | 2 | 1

D D

Design Name:; Rev; Page Name:; Size; Date:; Sheet; DEMO; Monday, October 20, 2025; Block_Diagram; IN_Power; P01_IN_Power; T1IN R1OUT; USB_DP; USB_DM; MCU; P02_MCU; PA13_DIAG; PA9_USART1_TX PA10_USART1_RX; PA11_DM/CAN_RX PA12_DP/CAN_TX; PC15_HEAT_PWM; PA2_PWM PA4_PWM PA3_PWM; PB10_PWM; PA8_FAN1_FG; PC13_PWM; FAN0_CTRL_PWR; PB6_DIR; PB7_STEP; PA15_PDN_UART; StepStick_Driver; P03_StepStick_Driver; ENN STEP DIR; PDN_UART DIAG; Other; P04_Other; FAN0_FG; Signal_PWM Zmin_Probe; FAN3_PWM; FAN2_PWM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

D D

## Vre = 0.596V


D D


D D


D D

## 加热棒


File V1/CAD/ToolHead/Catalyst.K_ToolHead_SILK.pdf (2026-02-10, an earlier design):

# ART FILM - adt

D4


# ART FILM - adb

# FAN1


# ART FILM - silktop

D4


# ART FILM - silkbotm

# FAN1


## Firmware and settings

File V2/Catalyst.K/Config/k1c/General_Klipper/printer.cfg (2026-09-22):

[include mainsail.cfg]
# This file contains common pin mappings for the Fysetc Catalyst.K and Catalyst.K ToolHead board.
# To use this config, the firmware should be compiled for the STM32H723 or STM32G431 .
# When calling "make menuconfig", enable "extra low-level configuration setup"
# and select the "25MHZ/12MHz crystal" as clock reference
# For flashing, write the compiled klipper.bin to memory location 0x08000000

# See docs/Config_Reference.md for a description of parameters.

## *** THINGS TO CHANGE/CHECK: ***
## MCU paths							[mcu] section
## rotation_distance                    [stepper_x], [stepper_y] and [extruder] section
## Thermistor types						[extruder] and [heater_bed] sections - See 'sensor types' list at end of file
## Z Endstop Switch location			[scanner] section, if you are using other probes, refer to [probe].
## Homing end position		     		[gcode_macro G32] section
## Z Endstop Switch  offset for Z0		[stepper_z] section
## Probe points							[bed_mesh] section
## PID tune								[extruder] and [heater_bed] sections
## Fine tune E steps					[extruder] section
## custom print start                   [PRINT_START] section

[force_move]
enable_force_move: true

[mcu]
##  You need to select 'Communication interface' to USB in 'make menuconfig'
##  when you compile Klipper for Catalyst.K_Kit
##	Obtain definition by "ls -l /dev/serial/by-id/"
##--------------------------------------------------------------------
serial: /dev/serial/by-id/usb-Klipper_stm32h723xx_1D0017000F51333235363331-if00
# canbus_uuid=4e86b8ca91ec
# canbus_interface: can2

[printer]
kinematics: corexy
max_velocity: 500  
max_accel: 1000			        
max_z_velocity: 15			    
max_z_accel: 350
square_corner_velocity: 5.0


[mcu ToolHead]
serial: /dev/serial/by-id/usb-wch.cn_USB_Dual_Serial_0123456789-if00
baud: 250000
restart_method: command

[mcu leveling_mcu]
serial: /dev/serial/by-id/usb-wch.cn_USB_Dual_Serial_0123456789-if02
baud: 250000
restart_method: command

[load_cell_probe]
sensor_type: hx711
sclk_pin: leveling_mcu:PA7
dout_pin: leveling_mcu:PA4
sample_rate: 80
gain: A-128
sensor_orientation: inverted
force_safety_limit: 2000
trigger_force: 120
drift_filter_cutoff_frequency: 0.8
drift_filter_delay: 2
buzz_filter_cutoff_frequency: 39.5
buzz_filter_delay: 2
notch_filter_frequencies: 21, 11
notch_filter_quality: 2.0
tare_time: 0.5
z_offset: 0
speed: 3
samples: 3
sample_retract_dist: 3
lift_speed: 5
# samples_result: average 
samples_result: median
samples_tolerance: 0.05
samples_tolerance_retries: 5

[extruder]
step_pin: ToolHead:PB7
dir_pin: ToolHead:PB6
enable_pin: !ToolHead:PB9

##  Update value below when you perform extruder calibration
##  If you ask for 100mm of filament, but in reality it is 98mm:
##  rotation_distance = <previous_rotation_distance> * <actual_extrude_distance> / 100
##  6.9 is a good starting point 
rotation_distance: 6.9
microsteps: 16
full_steps_per_rotation: 200
nozzle_diameter: 0.400
filament_diameter: 1.75
heater_pin: ToolHead:PC15
## Check what thermistor type you have. See https://www.klipper3d.org/Config_Reference.html#common-thermistors for common thermistor types.
sensor_type: EPCOS 100K B57560G104F
sensor_pin: ToolHead:PB2 
pullup_resistor: 4700
min_temp: 0 
max_temp: 320
min_extrude_temp: 10
# pid_Kp: 25.013
# pid_Ki: 2.566
# pid_Kd: 60.966
pressure_advance: 0.04
pressure_advance_smooth_time: 0.040
max_extrude_cross_section: 5000.0
max_extrude_only_distance: 1500

[tmc2209 extruder]
uart_pin: ToolHead:PA15
interpolate: false
run_current: 0.5
sense_resistor: 0.110
stealthchop_threshold: 0
##diag_pin: ToolHead:PA13


#####################################################################
#      X/Y Stepper Settings
#####################################################################

[stepper_x]
##	Connected to X-MOT
step_pin: PE11
dir_pin: !PE10
enable_pin: !PE9
rotation_distance: 40
microsteps: 16
full_steps_per_rotation:200 
endstop_pin: tmc2209_stepper_x:virtual_endstop
position_min: 0
position_endstop: 220
position_max: 220
homing_speed: 30
homing_retract_dist: 0
homing_positive_dir: true

[tmc2209 stepper_x]
uart_pin: PE7
interpolate: True
run_current: 0.8
# hold_current: 0.8
sense_resistor: 0.110
stealthchop_threshold: 0
diag_pin:^PE0
driver_SGTHRS: 75


[stepper_y]
##	Connected to Y-MOT
step_pin: PD8
dir_pin: !PB12
enable_pin: !PD9
rotation_distance: 40
microsteps: 16
full_steps_per_rotation:200
endstop_pin: tmc2209_stepper_y:virtual_endstop
position_min: 0
position_endstop: 0
position_max: 220
homing_speed: 25
homing_retract_dist: 0
homing_positive_dir: false

[tmc2209 stepper_y]
uart_pin: PE15
interpolate: True
run_current: 0.8
# hold_current: 0.8
sense_resistor: 0.110
stealthchop_threshold: 0
diag_pin:^PB13
driver_SGTHRS: 50

##	Connected to Z-MOT
[stepper_z]
step_pin: PD14
dir_pin: !PD13
enable_pin: !PD15
rotation_distance: 8
full_steps_per_rotation: 200
gear_ratio: 64:20
microsteps: 16
endstop_pin: probe:z_virtual_endstop 
position_max: 250
position_min: -10
homing_speed: 10
second_homing_speed: 1
homing_retract_dist: 2.0

[tmc2209 stepper_z]
uart_pin: PD10
uart_address: 0
interpolate: True
run_current: 0.8
hold_current: 0.5
sense_resistor: 0.110
stealthchop_threshold: 0

## Connected to E0-MOT
# [stepper_z1]
# step_pin: PD5
# dir_pin: PD6
# enable_pin: !PD4
# rotation_distance: 8
# gear_ratio: 27:1
# microsteps: 16

# [tmc2209 stepper_z1]
# uart_pin: PD7
# uart_address: 0
# interpolate: True
# run_current: 1.5
# hold_current: 0.5
# sense_resistor: 0.110
# stealthchop_threshold: 0
# #diag_pin:PG2

## Connected to E1-MOT
# [stepper_z2]
# step_pin: PE6
# dir_pin: PC13
# enable_pin: !PE5
# rotation_distance: 40
# gear_ratio: 27:1
# microsteps: 16

# [tmc2209 stepper_z2]
# uart_pin: PC14
# uart_address: 0
# interpolate: True
# run_current: 1.5
# hold_current: 0.5
# sense_resistor: 0.110
# stealthchop_threshold: 0

# # [stepper_x] for tmc5160, The homing sensitivity for the limit-switchless homing mode needs to be adjusted.
# [stepper_x]
# ##	Connected to X-MOT
# step_pin: PE11
# dir_pin: !PE10
# enable_pin: !PE9
# rotation_distance: 40
# microsteps: 16
# full_steps_per_rotation:200 
# endstop_pin: tmc5160_stepper_x:virtual_endstop
# position_min: 0
# position_endstop: 306
# position_max: 306
# homing_speed: 30
# homing_retract_dist: 0
# homing_positive_dir: true

# [tmc5160 stepper_x]
# cs_pin: PE7
# spi_software_mosi_pin: PE14
# spi_software_miso_pin: PE13
# spi_software_sclk_pin: PE12
# run_current: 1.5
# hold_current: 0.8
# sense_resistor: 0.075
# stealthchop_threshold: 0
# diag0_pin: ^!PE0
# driver_SGT: 30

# # [stepper_y] for tmc5160, The homing sensitivity for the limit-switchless homing mode needs to be adjusted.
# [stepper_y]
# ##	Connected to Y-MOT
# step_pin: PD8
# dir_pin: !PB12
# enable_pin: !PD9
# rotation_distance: 40
# microsteps: 16
# full_steps_per_rotation:200
# endstop_pin: tmc5160_stepper_y:virtual_endstop
# position_min: 0
# position_endstop: 306
# position_max: 306
# homing_speed: 25
# homing_retract_dist: 0
# homing_positive_dir: true

# [tmc5160 stepper_y]
# cs_pin: PE15
# spi_software_mosi_pin: PE14
# spi_software_miso_pin: PE13
# spi_software_sclk_pin: PE12
# run_current: 2.0
# hold_current: 0.8
# sense_resistor: 0.075
# stealthchop_threshold: 0
# diag0_pin:^!PB13
# driver_SGT: 30

# [stepper_z]
# step_pin: PD14
# dir_pin: !PD13
# enable_pin: !PD15
# rotation_distance: 8
# full_steps_per_rotation: 200
# gear_ratio: 64:20
# microsteps: 16
# endstop_pin: probe:z_virtual_endstop 
# position_max: 290
# position_min: -10
# homing_speed: 10
# second_homing_speed: 1
# homing_retract_dist: 2.0

# [tmc5160 stepper_z]
# cs_pin: PD10
# spi_software_mosi_pin: PE14
# spi_software_miso_pin: PE13
# spi_software_sclk_pin: PE12
# interpolate: True
# run_current: 2.0
# hold_current: 0.5
# sense_resistor: 0.075
# stealthchop_threshold: 0
# # diag_pin:^!PE1
# # driver_SGT: 30

# # [stepper_z1]
# # step_pin: PD5
# # dir_pin: PD6
# # enable_pin: !PD4
# # rotation_distance: 8
# # microsteps: 16
# # gear_ratio: 64:20
# # full_steps_per_rotation:200 

# # [tmc5160 stepper_z1]
# # cs_pin: PD7
# # spi_software_mosi_pin: PE14
# # spi_software_miso_pin: PE13
# # spi_software_sclk_pin: PE12
# # run_current: 2.0
# # hold_current: 0.5
# # sense_resistor: 0.075
# # stealthchop_threshold: 0
# # # diag_pin:^!PC4
# # # driver_SGT: 30


# # [stepper_z2]
# # step_pin: PE6
# # dir_pin: PC13
# # enable_pin: !PE5
# # rotation_distance: 8
# # microsteps: 16
# # gear_ratio: 64:20
# # full_steps_per_rotation:200 

# # [tmc5160 stepper_z2]
# # cs_pin: PC14
# # spi_software_mosi_pin: PE14
# # spi_software_miso_pin: PE13
# # spi_software_sclk_pin: PE12
# # run_current: 2.0
# # hold_current: 0.5
# # sense_resistor: 0.075
# # stealthchop_threshold: 0
# # # diag_pin:^!PD12
# # # driver_SGT: 30
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

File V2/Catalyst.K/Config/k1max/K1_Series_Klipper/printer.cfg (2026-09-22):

# K1-MAX
# Printer_size: 300x300x300
# Version: v1.0.3
# CreateDate: 2026/04/30
# ToolHead: chip: stm32g431
# bed_mcu: chip: GD32E230F8P6
# mcu: chip: stm32h723

[include sensorless.cfg]
[include gcode_macro.cfg]
[include printer_params.cfg]

[mcu]
serial: /dev/serial/by-id/usb-Klipper_stm32h723xx_12345-if00

[mcu ToolHead]
serial: /dev/serial/by-id/usb-Klipper_stm32g431xx_54005A000850454B52343920-if00
#serial: /dev/serial/by-id/usb-Klipper_stm32g431xx_13452-if00

[mcu bed_mcu]
serial: /dev/serial/by-id/usb-wch.cn_USB_Dual_Serial_0123456789-if02
baud: 230400
restart_method: command

[verify_heater extruder]
[verify_heater heater_bed]
check_gain_time: 2400
heating_gain: 1.0
hysteresis: 10

# [mcu rpi]
# serial: /tmp/klipper_host_mcu

# [bl24c16f]
# i2c_mcu: rpi
# i2c_bus: i2c.2
# i2c_speed: 400000

[idle_timeout]
timeout: 99999999

[virtual_sdcard]
path: /home/linaro/printer_data/gcodes

[gcode_arcs]
resolution: 1.0

[temperature_sensor mcu_temp]
sensor_type: temperature_mcu
min_temp: 0
max_temp: 100

[temperature_sensor chamber_temp]
sensor_type: EPCOS 100K B57560G104F
sensor_pin: PC1
min_temp: 0
max_temp: 125

[duplicate_pin_override]
pins: PB2, PC1

[temperature_fan chamber_fan]
pin: PB2
cycle_time: 0.0100
hardware_pwm: false
max_power: 1
shutdown_speed: 0
sensor_type: EPCOS 100K B57560G104F
sensor_pin: PC1
min_temp: 0
max_temp: 70
control: watermark
max_delta: 2
target_temp: 35.0
max_speed: 1.0
min_speed: 0.0

[stepper_x]
step_pin: PE11
dir_pin: !PE10
enable_pin: !PE9
microsteps: 16
rotation_distance: 40
endstop_pin: tmc2209_stepper_x:virtual_endstop
position_endstop: 306.5
position_min: -2
position_max: 306.5
homing_speed: 30
homing_retract_dist:0

[tmc2209 stepper_x]
uart_pin:PE7
interpolate: True
run_current:1.0
# hold_current:0.5
sense_resistor: 0.110
stealthchop_threshold: 0
diag_pin: ^PE0
driver_IHOLDDELAY: 8
driver_TPOWERDOWN: 20
driver_TBL: 0
driver_TOFF: 1
driver_HEND: 0
driver_HSTRT: 0
driver_SGTHRS: 75

[stepper_y]
step_pin: PD8
dir_pin: !PB12
enable_pin: !PD9
microsteps: 16
rotation_distance: 40
endstop_pin: tmc2209_stepper_y:virtual_endstop
position_endstop: -2
position_min: -2
position_max: 306
homing_speed: 30
homing_retract_dist:0

[tmc2209 stepper_y]
uart_pin:PE15
interpolate: True
run_current:1.0
# hold_current:0.5
sense_resistor: 0.110
stealthchop_threshold: 0
diag_pin: ^PB13
driver_IHOLDDELAY: 8
driver_TPOWERDOWN: 20
driver_TBL: 0
driver_TOFF: 1
driver_HEND: 0
driver_HSTRT: 0
driver_SGTHRS: 70

[stepper_z]
step_pin: PD14
dir_pin: !PD13
enable_pin: !PD15
microsteps: 16
rotation_distance:8
full_steps_per_rotation: 200
gear_ratio: 64:20
endstop_pin: tmc2209_stepper_z:virtual_endstop
position_endstop: 0
position_max: 305
position_min: -10
homing_speed: 5
second_homing_speed: 1
homing_retract_dist: 2.0

[tmc2209 stepper_z]
uart_pin: PD10
run_current:1.0
hold_current:0.5
diag_pin: ^PE1
stealthchop_threshold: 0
sense_resistor: 0.110
# driver_IHOLDDELAY: 8
# driver_TPOWERDOWN: 20
# driver_TBL: 1
# driver_TOFF: 1
# driver_HEND: 2
# driver_HSTRT: 2
driver_SGTHRS: 0

# # [stepper_x] for tmc5160, The homing sensitivity for the limit-switchless homing mode needs to be adjusted.
# [stepper_x]
# ##	Connected to X-MOT
# step_pin: PE11
# dir_pin: !PE10
# enable_pin: !PE9
# rotation_distance: 40
# microsteps: 16
# full_steps_per_rotation:200 
# endstop_pin: tmc5160_stepper_x:virtual_endstop
# position_min: 0
# position_endstop: 306
# position_max: 306
# homing_speed: 30
# homing_retract_dist: 0
# homing_positive_dir: true

# [tmc5160 stepper_x]
# cs_pin: PE7
# spi_software_mosi_pin: PE14
# spi_software_miso_pin: PE13
# spi_software_sclk_pin: PE12
# run_current: 1.5
# hold_current: 0.8
# sense_resistor: 0.110
# stealthchop_threshold: 0
# diag0_pin: ^!PE0
# driver_SGT: 30

# # [stepper_y] for tmc5160, The homing sensitivity for the limit-switchless homing mode needs to be adjusted.
# [stepper_y]
# ##	Connected to Y-MOT
# step_pin: PD8
# dir_pin: !PB12
# enable_pin: !PD9
# rotation_distance: 40
# microsteps: 16
# full_steps_per_rotation:200
# endstop_pin: tmc5160_stepper_y:virtual_endstop
# position_min: 0
# position_endstop: 306
# position_max: 306
# homing_speed: 25
# homing_retract_dist: 0
# homing_positive_dir: true

# [tmc5160 stepper_y]
# cs_pin: PE15
# spi_software_mosi_pin: PE14
# spi_software_miso_pin: PE13
# spi_software_sclk_pin: PE12
# run_current: 2.0
# hold_current: 0.8
# sense_resistor: 0.110
# stealthchop_threshold: 0
# diag0_pin:^!PB13
# driver_SGT: 30

# [stepper_z]
# step_pin: PD14
# dir_pin: !PD13
# enable_pin: !PD15
# rotation_distance: 8
# full_steps_per_rotation: 200
# gear_ratio: 64:20
# microsteps: 16
# endstop_pin: probe:z_virtual_endstop 
# position_max: 290
# position_min: -10
# homing_speed: 10
# second_homing_speed: 1
# homing_retract_dist: 2.0

# [tmc5160 stepper_z]
# cs_pin: PD10
# spi_software_mosi_pin: PE14
# spi_software_miso_pin: PE13
# spi_software_sclk_pin: PE12
# interpolate: True
# run_current: 2.0
# hold_current: 0.5
# sense_resistor: 0.110
# stealthchop_threshold: 0
# # diag_pin:^!PE1
# # driver_SGT: 30

[extruder]
max_extrude_only_distance: 1000.0
max_extrude_cross_section: 80
step_pin: ToolHead:PB7
dir_pin: ToolHead:PB6
enable_pin: !ToolHead:PB9
microsteps: 16
rotation_distance: 6.9
nozzle_diameter: 0.400
filament_diameter: 1.750
heater_pin: ToolHead:PC15
sensor_type: EPCOS 100K B57560G104F
sensor_pin: ToolHead:PB2
pressure_advance: 0.04
pressure_advance_smooth_time: 0.040
control: pid
pid_Kp: 25.013
pid_Ki: 2.566
pid_Kd: 60.966
# pid_Kp: 60
# pid_Ki: 0.1
# pid_Kd: 5
min_temp: 0
max_temp: 320

[tmc2209 extruder]
uart_pin: ToolHead:PA15
run_current: 0.8
sense_resistor: 0.110
stealthchop_threshold: 0

[heater_bed]
heater_pin: !PB0
sensor_type: EPCOS 100K B57560G104F
sensor_pin: PC0
control: pid
pid_Kp: 37
pid_Ki: 0.18
pid_Kd: 280
min_temp: 0
max_temp: 125

[filament_switch_sensor filament_sensor]
pause_on_runout: true
switch_pin: !PE8
runout_gcode:
  {% if printer.extruder.can_extrude|lower == 'true' %}
    G91
    G0 E30 F600
    G90
  {% endif %}

[filament_switch_sensor filament_sensor_2]
pause_on_runout: false
switch_pin: ToolHead:PC14
# switch_pin: !ToolHead:PC14

[multi_pin heater_fans]
pins: ToolHead:PB5

[heater_fan hotend_fan]
pin: multi_pin:heater_fans
heater: extruder
heater_temp: 40

# Turn on the fan on the second layer of the extruder.
[output_pin fan0]
pin: ToolHead:PA14
pwm: True
cycle_time: 0.0100
hardware_pwm: false
value: 0.00
scale: 255
shutdown_value: 0.0

# Bottom Motherboard Cooling Fan
[output_pin fan1]
pin: PB10
pwm: True
cycle_time: 0.0100
hardware_pwm: false
value: 0.00
scale: 255
shutdown_value: 0.0

# Auxiliary Fan
[output_pin fan2]
pin: PA3
pwm: True
cycle_time: 0.0100
hardware_pwm: false
value: 0.00
scale: 255
shutdown_value: 0.0

[output_pin LED]
pin: PD12
pwm: True
cycle_time: 0.010
value: 1

# [output_pin power]
# pin: ToolHead:PB3
# pwm: False
# value: 1

[adxl345]
cs_pin: ToolHead:PA0
spi_speed: 5000000
axes_map: x,-z,y
spi_software_sclk_pin: ToolHead:PA5
spi_software_mosi_pin: ToolHead:PA7
spi_software_miso_pin: ToolHead:PA6

[resonance_tester]
accel_chip: adxl345
accel_per_hz: 75
# min_freq: 30
# max_freq: 100
probe_points:
   150,150,10

[prtouch_v2]
pr_version: 2
step_base: 2
z_offset: 0     
noz_ex_com: 0.09 
tilt_corr_dis:0.05
tri_min_hold: 4000,10000
tri_max_hold: 14000,60000
pres_cnt: 4
tri_need_cnt: 1
best_above_z: 5
pres0_clk_pins: bed_mcu:PA7
pres0_sdo_pins: bed_mcu:PA4
pres1_clk_pins: bed_mcu:PA6
pres1_sdo_pins: bed_mcu:PA3
pres2_clk_pins: bed_mcu:PA2
pres2_sdo_pins: bed_mcu:PA0
pres3_clk_pins: bed_mcu:PA5
pres3_sdo_pins: bed_mcu:PA1
# show_msg: True
# tri_wave_ip: 192.168.0.147
step_swap_pin: PE4
pres_swap_pin: bed_mcu:PB1
g28_wait_cool_down: true
pa_clr_down_mm: -0.15
clr_noz_start_x: 130
clr_noz_start_y: 295
clr_noz_len_x: 40
clr_noz_len_y: 2
speeds: 2.5,1.0
tri_hftr_cut: 2,1
tri_lftr_k1: 0.50,0.15

tri_acq_ms: 5
tri_send_ms: 5

tri_min_hold_1:6000,10000
tri_min_hold_2:6000,10000
tri_min_hold_3:6000,10000
tri_min_hold_4:6000,10000
tri_min_hold_5:6000,10000
tri_min_hold_6:6000,10000

tri_min_hold_7:6000,10000
tri_min_hold_8:6000,10000
tri_min_hold_9:6000,10000
tri_min_hold_10:6000,10000
tri_min_hold_11:6000,10000
tri_min_hold_12:6000,10000

tri_min_hold_13:6000,10000
tri_min_hold_14:6000,10000
tri_min_hold_15:6000,10000
tri_min_hold_16:6000,10000
tri_min_hold_17:6000,10000
tri_min_hold_18:6000,10000

tri_min_hold_19:6000,10000
tri_min_hold_20:6000,10000
tri_min_hold_21:6000,10000
tri_min_hold_22:6000,10000
tri_min_hold_23:6000,10000
tri_min_hold_24:6000,10000

tri_min_hold_25:6000,10000
tri_min_hold_26:6000,10000
tri_min_hold_27:6000,10000
tri_min_hold_28:6000,10000
tri_min_hold_29:6000,10000
tri_min_hold_30:6000,10000

tri_min_hold_31:6000,10000
tri_min_hold_32:6000,10000
tri_min_hold_33:6000,10000
tri_min_hold_34:6000,10000
tri_min_hold_35:6000,10000
tri_min_hold_36:6000,10000
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

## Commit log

2026-02-10 Switch image
2026-02-12 fix name
    [1.dwg, BOARD.dxf, CAD.dxf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]
2026-02-14 add 3D file
    [Catalyst.K Connector Instruction.dxf, Catalyst.K_2D.dxf, Catalyst.K_ToolHead_2D.dxf]
2026-09-21 update v2
    [Catalyst.K Connector Instruction.dxf, Catalyst.K_2D.dxf, Catalyst.K_ToolHead_2D.dxf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]
2026-09-23 Update leveling.cfg
    Reduced speed from 3 > 2
    [leveling.cfg]
